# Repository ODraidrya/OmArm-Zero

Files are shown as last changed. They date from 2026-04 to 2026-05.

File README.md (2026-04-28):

# OmArm Zero

**6-DOF (5+1 Gripper) 3D-Printed Robotic Arm with ESP32 WiFi Web Control**

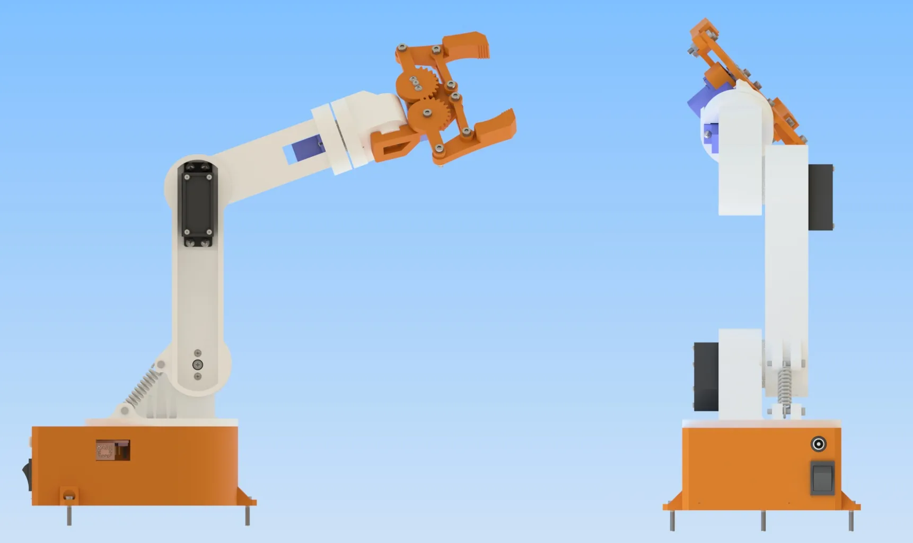
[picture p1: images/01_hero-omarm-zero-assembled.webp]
OmArm Zero






---

## Overview

OmArm Zero is a fully 3D-printed robotic arm with 6 degrees of freedom (5 arm joints + 1 gripper), controlled wirelessly over WiFi from any phone or laptop browser — no app required.

Connect to the ESP32's WiFi network, open `10.10.10.1` in any browser, and move the arm with sliders. Total cost: under $50.

## Specifications

| Parameter | Value |
|---|---|
| Degrees of Freedom | 6 (5 arm joints + 1 gripper) |
| Maximum Reach | 303 mm |
| Rated Payload | 141 g (150 g max) |
| Servos | 3x MG996R (metal gear) + 3x SG90 |
| Controller | ESP32 DevKit V1 |
| PWM Driver | PCA9685 16-channel (I2C) |
| Power | 5V 10A DC supply |
| WiFi | Access Point mode (no router needed) |
| Web Interface | Browser-based GUI with PWA support |
| Serial Interface | 115200 baud (ROS 2 compatible) |
| Total BOM Cost | ~$48 |

## Repository Structure

```
OmArm-Zero/
├── firmware/
│   ├── OmArmZeroControl/       # Main WiFi web control firmware
│   ├── OmArmZero_LittleFS/     # LittleFS uploader + web interface
│   │   └── data/               # HTML, CSS, JS served from ESP32 flash
│   ├── ros2_serial/            # Serial firmware for ROS 2 integration
│   └── test/
│       ├── I2C_Scanner/        # I2C device scanner (debug)
│       └── Calibration_SendToHome/  # Home position calibration (0°)
├── electronics/
│   ├── wiring-diagram.png      # Fritzing breadboard view
│   ├── omarm-zero.fzz          # Fritzing source file
│   └── bom.html                # Bill of Materials
├── images/                     # Documentation images
├── LICENSE                     # MIT License
└── README.md
```

## Quick Start

### 1. Hardware Required

| # | Component | Qty |
|---|---|-----|
| 1 | ESP32 DevKit V1 (30-pin) | 1 |
| 2 | PCA9685 16-Channel PWM Servo Driver | 1 |
| 3 | MG996R Servo Motor (metal gear) | 3 |
| 4 | SG90 Micro Servo | 3 |
| 5 | 5V 10A DC Power Supply | 1 |
| 6 | 686ZZ Bearing (6x13x5 mm) | 1 |
| 7 | Extension Spring (4 mm OD, 15 mm) | 1 |
| 8 | M3, M1.6, No.2, No.3 screws | assorted |

### 2. Wiring

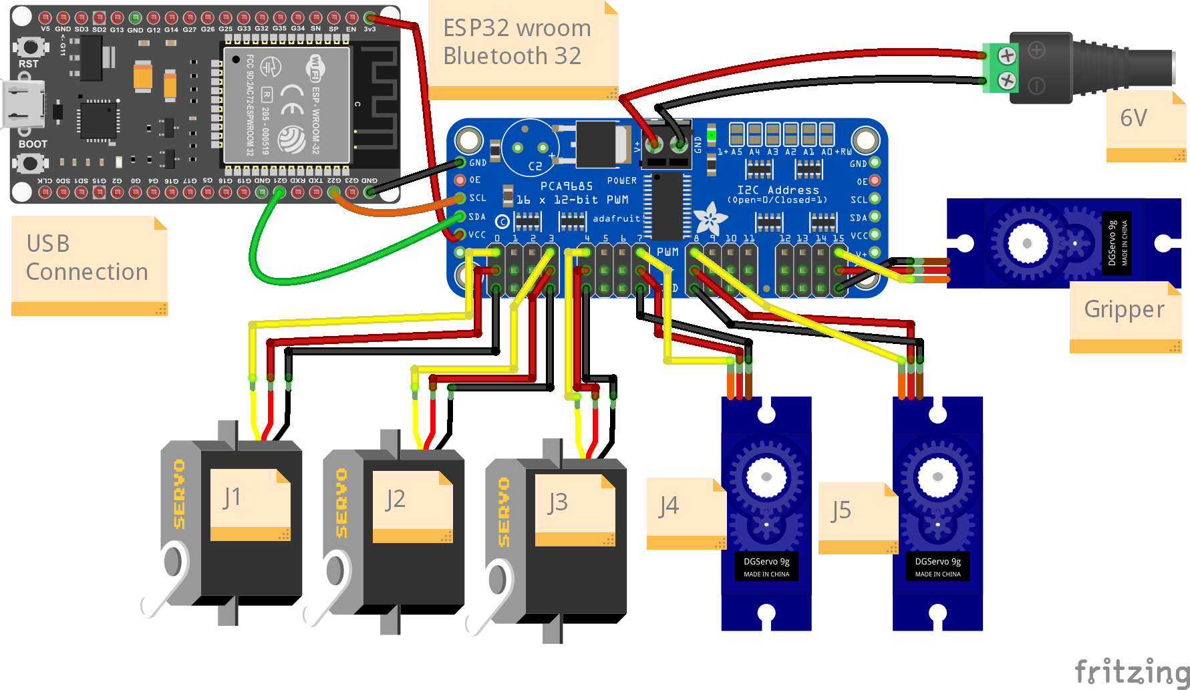
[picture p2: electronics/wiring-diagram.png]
Wiring Diagram


| PCA9685 Channel | Joint | Servo |
|---|---|---|
| 0 | J1 — Base rotation | MG996R |
| 1 | J2 — Shoulder | MG996R |
| 2 | J3 — Elbow | MG996R |
| 3 | J4 — Wrist pitch | SG90 |
| 4 | J5 — Wrist roll | SG90 |
| 5 | J6 — Gripper | SG90 |

**I2C connections:** PCA9685 SDA → GPIO 21, SCL → GPIO 22, Address: 0x40

**Power:** Connect the 5V 10A supply directly to the PCA9685 V+ terminal. Do NOT power servos from ESP32.

### 3. Flash Firmware

**Prerequisites:**
- Arduino IDE 2.x
- ESP32 board package (Espressif Systems)
- Libraries: `Adafruit_PWMServoDriver`, `Wire`, `WiFi`, `WebServer`, `LittleFS`

**Step 1 — Upload web interface to LittleFS:**

1. Install the [ESP32 LittleFS Upload Plugin](https://github.com/lorol/arduino-esp32littlefs-plugin)
2. Open `firmware/OmArmZero_LittleFS/OmArmZero_LittleFS.ino`
3. Use **Tools → ESP32 Sketch Data Upload** to flash the `data/` folder
4. Or: upload the sketch itself which creates the files programmatically

**Step 2 — Upload main firmware:**

1. Open `firmware/OmArmZeroControl/OmArmZeroControl.ino`
2. Select board: **ESP32 Dev Module**
3. Upload

### 4. Connect and Control

1. Power on the arm (5V supply + USB to ESP32)
2. Connect your phone/laptop to WiFi network: **OmArmZero**
3. Open browser: **http://10.10.10.1**
4. Move sliders to control each joint

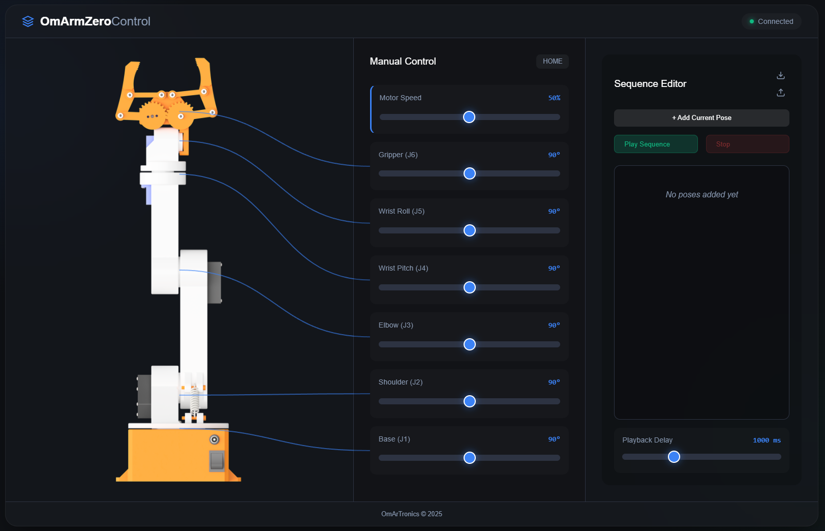
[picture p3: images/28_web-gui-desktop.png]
Web GUI


## Web Interface Features

- 6 individual joint sliders with real-time control
- Sequence recorder — save and replay motion sequences
- Home button — return all joints to 0° position
- PWA support — add to home screen for app-like experience
- Responsive design — works on mobile and desktop
- No internet required — runs entirely on ESP32's local network

## ROS 2 Integration

For ROS 2 Jazzy integration, flash `firmware/ros2_serial/omarm_zero_ros2_serial.ino` instead. This provides a serial protocol (115200 baud) compatible with the `ros2_control` hardware interface.

Serial command format: `J<joint_id>:<angle>\n` (e.g., `J1:90\n`)

## Calibration

Before first use, flash `firmware/test/Calibration_SendToHome/Calibration_SendToHome.ino` to set all servos to the 0° home position. Assemble the arm with all joints at 0°.

## Troubleshooting

| Issue | Solution |
|---|---|
| PCA9685 not found | Run `firmware/test/I2C_Scanner/` to check I2C address |
| Servos jitter | Ensure dedicated 5V 10A supply, not USB power |
| WiFi won't connect | Default SSID: `OmArmZero`, no password |
| Web page won't load | Verify LittleFS upload succeeded (Step 1) |

## 3D Print Files

STL files, STEP source, and the full 70-page PDF build guide are available as a complete package:

- **Cults3D:** [OmArm Zero — Complete Package](https://cults3d.com/en/3d-model/gadget/omarm-zero-6-dof-5-1-gripper-robotic-arm-esp32-wifi-control-stl-step)
- **OmArTronics Shop:** [Project Package](https://omartronics.com/product/omarm-zero-6dof-esp32-robotic-arm/)

## Links

- [Full Build Guide (Blog)](https://omartronics.com/omarm-zero-build-5-dof-robotic-arm-esp32-web-control/)
- [YouTube Build Video](https://youtu.be/smRG6uzNHag)
- [OmArTronics Website](https://omartronics.com/)

## License

This firmware is released under the **MIT License** — see [LICENSE](LICENSE).

**Note:** The 3D-printable CAD files (STL, STEP) and the PDF build guide are sold separately and are for personal, non-commercial use only. This repository contains only the firmware and web interface source code.

## Author

[OmArTronics](https://omartronics.com)

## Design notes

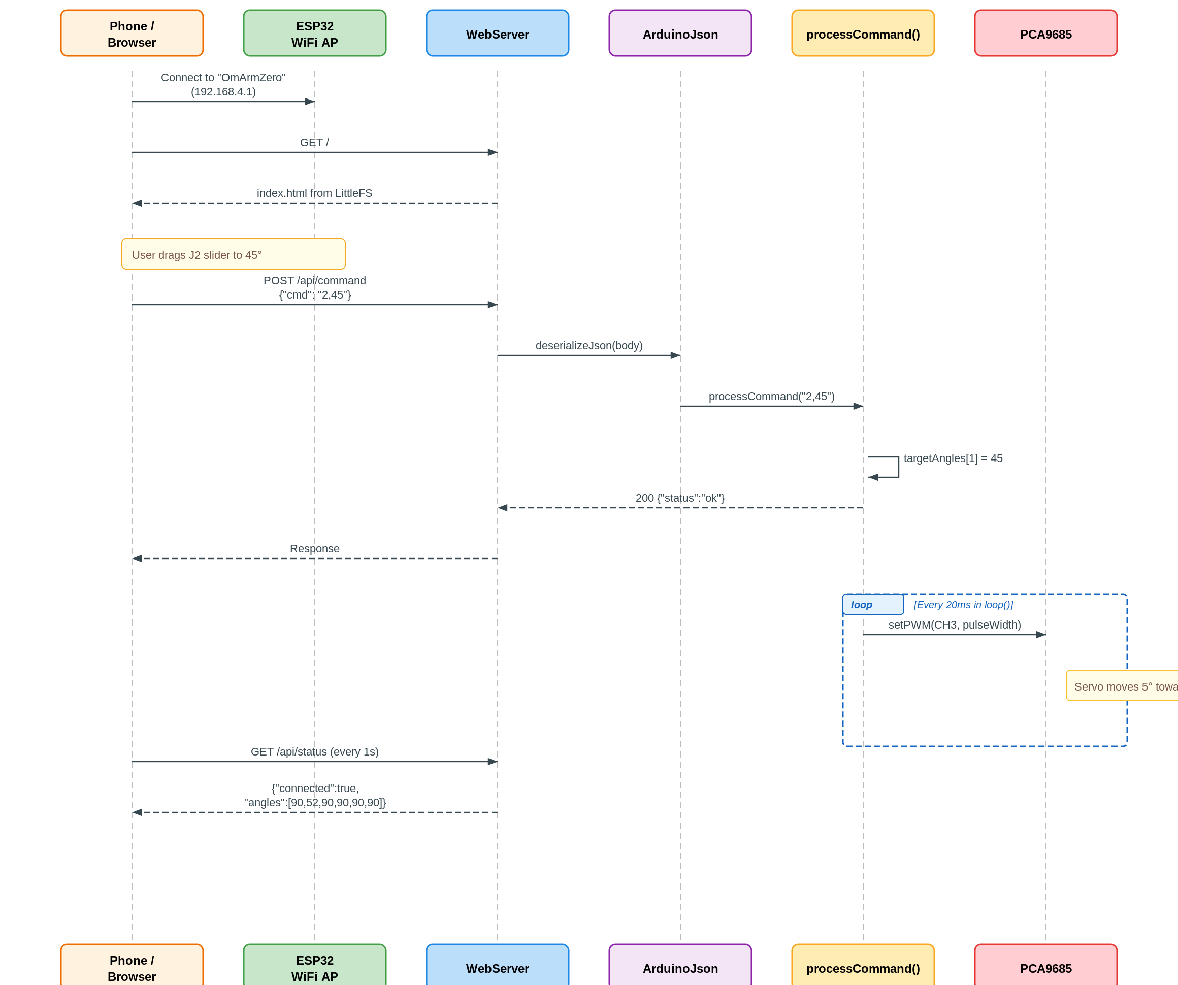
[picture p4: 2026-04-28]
images/08_web-gui-sequence-diagram.png

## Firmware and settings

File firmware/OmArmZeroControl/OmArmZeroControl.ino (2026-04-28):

/*
 * OmArm Zero Control Firmware
 * Für 6-DOF (5+1 Gripper) Roboterarm (6 Servos)
 * 
 * Hardware:
 * - ESP32 DevKit
 * - PCA9685 16-Channel PWM Driver (I2C: SDA=21, SCL=22)
 * - 3x MG996R Servo (J1, J2, J3)
 * - 3x SG90 Micro Servo (J4, J5, Gripper/J6)
 * 
 * Protokoll:
 * - Baud: 115200
 * - Commands:
 *   MOVE:d1,d2,d3,d4,d5,d6\n      - Move to positions (0-180°)
 *   HOME\n                        - Move to home position (0°)
 *   STATUS\n                      - Return current positions
 */

#include <Wire.h>
#include <Adafruit_PWMServoDriver.h>

// PCA9685 Setup
Adafruit_PWMServoDriver pwm = Adafruit_PWMServoDriver(0x40);

// Servo Configuration
#define NUM_SERVOS 6
// Channels für J1-J6 (Beibehalten der ersten 6 Kanäle des alten Codes)
const uint8_t SERVO_CHANNELS[NUM_SERVOS] = {0, 3, 4, 7, 8, 11};
const char* SERVO_NAMES[NUM_SERVOS] = {"J1", "J2", "J3", "J4", "J5", "Gripper"};

// PWM Pulse Width (us) for 0° and 180°
// MG996R (J1-J3): 500-2500us
// SG90 (J4-J6): 500-2400us
const uint16_t SERVO_MIN_PULSE[NUM_SERVOS] = {500, 500, 500, 500, 500, 500};
const uint16_t SERVO_MAX_PULSE[NUM_SERVOS] = {2500, 2500, 2500, 2400, 2400, 2400};

// Current positions (degrees 0-180)
int currentPos[NUM_SERVOS] = {0, 0, 0, 0, 0, 0};
int targetPos[NUM_SERVOS] = {0, 0, 0, 0, 0, 0};

// Safety limits (degrees)
const int MIN_ANGLE = 0;
const int MAX_ANGLE = 180;

// Movement speed (degrees per update cycle)
int movementSpeed = 5;
int updateIntervalMs = 20;  // 50Hz update rate

// Timing
unsigned long lastUpdateTime = 0;
unsigned long lastStatusTime = 0;

// Serial buffer
String serialBuffer = "";

void setup() {
  // Serial setup
  Serial.begin(115200);
  while (!Serial && millis() < 3000); // Wait max 3 seconds
  
  Serial.println("\n╔════════════════════════════════════════════╗");
  Serial.println("║  OmArm Zero Control Firmware             ║");
  Serial.println("║  Konfig: 6-DOF (5+1 Gripper, 6 Servos)   ║");
  Serial.println("╚════════════════════════════════════════════╝");
  
  // I2C Setup
  Wire.begin(21, 22); // SDA=21, SCL=22
  delay(100);
  
  // PCA9685 Setup
  pwm.begin();
  pwm.setOscillatorFrequency(27000000);
  pwm.setPWMFreq(50); // 50Hz for servos
  delay(100);
  
  Serial.println("✓ PCA9685 initialisiert");
  
  // Move to home position
  Serial.println("→ Fahre zu Home Position (0°)...");
  for (int i = 0; i < NUM_SERVOS; i++) {
    setServoAngle(i, 0);
    currentPos[i] = 0;
    targetPos[i] = 0;
    delay(50);
  }
  
  Serial.println("✓ System bereit!");
  Serial.println("Befehle: MOVE:d1,d2,d3,d4,d5,d6 | HOME | STATUS");
  Serial.println("─────────────────────────────────────────────");
}

void loop() {
  unsigned long now = millis();
  
  // Read serial commands
  readSerialCommands();
  
  // Smooth movement update at fixed rate
  if (now - lastUpdateTime >= updateIntervalMs) {
    lastUpdateTime = now;
    updateServoMovement();
  }
  
  // Periodic status (every 5 seconds if no commands)
  if (now - lastStatusTime > 5000) {
    lastStatusTime = now;
    // Uncomment for debug:
    // printStatus();
  }
}

void readSerialCommands() {
  while (Serial.available() > 0) {
    char c = Serial.read();
    
    if (c == '\n' || c == '\r') {
      if (serialBuffer.length() > 0) {
        processCommand(serialBuffer);
        serialBuffer = "";
      }
    } else {
      serialBuffer += c;
      
      // Safety: Prevent buffer overflow
      if (serialBuffer.length() > 128) {
        Serial.println("ERROR: Command too long");
        serialBuffer = "";
      }
    }
  }
}

void processCommand(String cmd) {
  cmd.trim();
  
  if (cmd.length() == 0) return;
  
  if (cmd.startsWith("MOVE:")) {
    handleMoveCommand(cmd.substring(5));
  }
  else if (cmd.startsWith("SPEED:")) {
    handleSpeedCommand(cmd.substring(6));
  }
  else if (isdigit(cmd.charAt(0))) {
    handleSingleJointCommand(cmd);
  }
  else if (cmd.equals("HOME")) {
    handleHomeCommand();
  }
  else if (cmd.equals("STATUS")) {
    handleStatusCommand();
  }
  else {
    Serial.print("ERROR: Unknown command: ");
    Serial.println(cmd);
  }
}

void handleSingleJointCommand(String cmd) {
  int commaIndex = cmd.indexOf(',');
  if (commaIndex == -1) return;
  
  int id = cmd.substring(0, commaIndex).toInt();
  int angle = cmd.substring(commaIndex + 1).toInt();
  
  // Convert 1-based ID to 0-based index
  int index = id - 1;
  
  if (index >= 0 && index < NUM_SERVOS) {
    angle = constrain(angle, MIN_ANGLE, MAX_ANGLE);
    targetPos[index] = angle;
  }
}

void handleMoveCommand(String params) {
  int values[NUM_SERVOS];
  int count = 0;
  
  // Parse comma-separated values
  int startIdx = 0;
  for (int i = 0; i <= params.length() && count < NUM_SERVOS; i++) {
    if (i == params.length() || params.charAt(i) == ',') {
      String val = params.substring(startIdx, i);
      val.trim();
      
      if (val.length() > 0) {
        values[count] = val.toInt();
        count++;
      }
      startIdx = i + 1;
    }
  }
  
  // Validate we got all values
  if (count != NUM_SERVOS) {
    Serial.print("ERROR: Expected ");
    Serial.print(NUM_SERVOS);
    Serial.print(" values, got ");
    Serial.println(count);
    return;
  }
  
  // Apply safety limits and set target positions
  for (int i = 0; i < NUM_SERVOS; i++) {
    int angle = constrain(values[i], MIN_ANGLE, MAX_ANGLE);
    
    if (angle != values[i]) {
      Serial.print("WARN: ");
      Serial.print(SERVO_NAMES[i]);
      Serial.print(" clamped ");
      Serial.print(values[i]);
      Serial.print("° → ");
      Serial.print(angle);
      Serial.println("°");
    }
    
    targetPos[i] = angle;
  }
  
  // Acknowledge
  Serial.println("OK: MOVE");
}

void handleSpeedCommand(String params) {
  int commaIndex = params.indexOf(',');
  if (commaIndex == -1) return;
  
  int newSpeed = params.substring(0, commaIndex).toInt();
  int newInterval = params.substring(commaIndex + 1).toInt();
  
  // Safety checks
  if (newSpeed >= 1 && newSpeed <= 20 && newInterval >= 5 && newInterval <= 50) {
    movementSpeed = newSpeed;
    updateIntervalMs = newInterval;
  }
}

void handleHomeCommand() {
  Serial.println("→ HOME");

  for (int i = 0; i < NUM_SERVOS; i++) {
    targetPos[i] = 0;
  }
  
  Serial.println("OK: HOME");
}

void handleStatusCommand() {
  Serial.print("STATUS:");
  for (int i = 0; i < NUM_SERVOS; i++) {
    Serial.print(currentPos[i]);
    if (i < NUM_SERVOS - 1) Serial.print(",");
  }
  Serial.println();
}

void updateServoMovement() {
  for (int i = 0; i < NUM_SERVOS; i++) {
    if (currentPos[i] != targetPos[i]) {
      
      // Move towards target with speed limit
      int diff = targetPos[i] - currentPos[i];
      int step = constrain(diff, -movementSpeed, movementSpeed);
      
      currentPos[i] += step;
      setServoAngle(i, currentPos[i]);
    }
  }
}

void setServoAngle(uint8_t servoIndex, int angle) {
  if (servoIndex >= NUM_SERVOS) return;
  
  // Clamp angle
  angle = constrain(angle, MIN_ANGLE, MAX_ANGLE);
  
  // Map angle to pulse width
  uint16_t minPulse = SERVO_MIN_PULSE[servoIndex];
  uint16_t maxPulse = SERVO_MAX_PULSE[servoIndex];
  uint16_t pulseWidth = map(angle, 0, 180, minPulse, maxPulse);
  
  // Convert to PCA9685 PWM value (4096 steps at 50Hz = 20ms)
  uint16_t pwmValue = (uint32_t)pulseWidth * 4096 / 20000;
  
  // Send to PCA9685
  pwm.setPWM(SERVO_CHANNELS[servoIndex], 0, pwmValue);
}

void printStatus() {
  Serial.println("\n─── Status ───");
  for (int i = 0; i < NUM_SERVOS; i++) {
    Serial.print(SERVO_NAMES[i]);
    Serial.print(": ");
    Serial.print(currentPos[i]);
    Serial.print("° → ");
    Serial.print(targetPos[i]);
    Serial.println("°");
  }
  Serial.println("──────────────");
}

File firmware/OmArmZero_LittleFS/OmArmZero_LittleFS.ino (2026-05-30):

/*
 * OmArm Zero LittleFS Firmware
 * 6-DOF (5+1 Gripper) Robot Arm (6 Servos) with Web Server + LittleFS
 * 
 * This version stores web files on the ESP32 filesystem (LittleFS).
 * Allows including large files like images.
 * 
 * Hardware:
 * - ESP32 DevKit
 * - PCA9685 16-Channel PWM Driver (I2C: SDA=21, SCL=22)
 * - 3x MG996R Servo (J1, J2, J3)
 * - 3x SG90 Micro Servo (J4, J5, Gripper/J6)
 * 
 * Upload Instructions:
 * 1. Install "ESP32 Sketch Data Upload" tool (Arduino 1.8) or use LittleFS plugin
 * 2. Tools -> ESP32 Sketch Data Upload (uploads /data folder)
 * 3. Upload this sketch normally
 * 
 * WiFi Access Point: "OmArmZero" (Password: "omarmcontrol")
 * Web Interface: http://10.10.10.1
 */

#include <Arduino.h>
#include <Wire.h>
#include <Adafruit_PWMServoDriver.h>
#include <WiFi.h>
#include <WebServer.h>
#include <LittleFS.h>
#include <ArduinoJson.h>

// WiFi Configuration
const char* ssid = "OmArmZero";
const char* password = "omarmcontrol";

// Web Server
WebServer server(80);

// PCA9685 Setup
Adafruit_PWMServoDriver pwm = Adafruit_PWMServoDriver(0x40);

// Servo Config
#define NUM_SERVOS 6
const uint8_t SERVO_CHANNELS[NUM_SERVOS] = {0, 3, 4, 7, 8, 11};
const uint16_t SERVO_MIN_PULSE[NUM_SERVOS] = {500, 500, 500, 500, 500, 500};
const uint16_t SERVO_MAX_PULSE[NUM_SERVOS] = {2500, 2500, 2500, 2400, 2400, 2400};

// State
int currentPos[NUM_SERVOS] = {0, 0, 0, 0, 0, 0};
int targetPos[NUM_SERVOS] = {0, 0, 0, 0, 0, 0};
int movementSpeed = 5;
unsigned long lastUpdateTime = 0;

// Function declarations
void setServoAngle(uint8_t servoIndex, int angle);
void updateServoMovement();
String getContentType(String filename);

// ------------------------------------------------------------------
// Web Server Handlers
// ------------------------------------------------------------------

void handleCommand() {
  if (!server.hasArg("plain")) {
    server.send(400, "application/json", "{\"error\":\"Body missing\"}");
    return;
  }
  
  String body = server.arg("plain");
  DynamicJsonDocument doc(512);
  if (deserializeJson(doc, body)) {
    server.send(400, "application/json", "{\"error\":\"Invalid JSON\"}");
    return;
  }

  String cmd = doc["cmd"];
  
  // STATUS check
  if (cmd.startsWith("STATUS")) {
    server.send(200, "application/json", "{\"status\":\"ok\"}");
    return;
  }
  
  // Joint Command: "1,90"
  if (isdigit(cmd.charAt(0))) {
    int comma = cmd.indexOf(',');
    if (comma != -1) {
      int id = cmd.substring(0, comma).toInt();
      int angle = cmd.substring(comma+1).toInt();
      if (id >= 1 && id <= 6) {
        targetPos[id-1] = constrain(angle, 0, 180);
      }
    }
  }
  // HOME
  else if (cmd.equals("HOME")) {
    for (int i = 0; i < 6; i++) targetPos[i] = 0;
  }
  // SPEED
  else if (cmd.startsWith("SPEED:")) {
    int comma = cmd.indexOf(',');
    if (comma != -1) {
      movementSpeed = cmd.substring(6, comma).toInt();
    }
  }
  // MOVE (Sequence Playback): "MOVE:90,90,90,90,90,90"
  else if (cmd.startsWith("MOVE:")) {
    String angles = cmd.substring(5);
    int idx = 0, start = 0;
    for (int i = 0; i <= angles.length() && idx < 6; i++) {
      if (i == angles.length() || angles.charAt(i) == ',') {
        targetPos[idx++] = constrain(angles.substring(start, i).toInt(), 0, 180);
        start = i + 1;
      }
    }
  }
  
  server.send(200, "application/json", "{\"status\":\"ok\"}");
}

// Serve files from LittleFS
void handleFileRequest() {
  String path = server.uri();
  
  if (path.endsWith("/")) {
    path += "index.html";
  }
  
  // Handle URL-encoded spaces
  path.replace("%20", " ");
  
  String contentType = getContentType(path);
  
  if (LittleFS.exists(path)) {
    File file = LittleFS.open(path, "r");
    server.streamFile(file, contentType);
    file.close();
  } else {
    server.send(404, "text/plain", "File Not Found: " + path);
  }
}

String getContentType(String filename) {
  if (filename.endsWith(".html")) return "text/html";
  else if (filename.endsWith(".css")) return "text/css";
  else if (filename.endsWith(".js")) return "application/javascript";
  else if (filename.endsWith(".json")) return "application/json";
  else if (filename.endsWith(".png")) return "image/png";
  else if (filename.endsWith(".jpg") || filename.endsWith(".jpeg")) return "image/jpeg";
  else if (filename.endsWith(".svg")) return "image/svg+xml";
  else if (filename.endsWith(".ico")) return "image/x-icon";
  return "text/plain";
}

// ------------------------------------------------------------------
// Setup & Loop
// ------------------------------------------------------------------

void setup() {
  Serial.begin(115200);
  
  // Initialize LittleFS
  if (!LittleFS.begin(true)) {
    Serial.println("LittleFS Mount Failed!");
    return;
  }
  Serial.println("LittleFS mounted successfully");
  
  // List files (debug)
  File root = LittleFS.open("/");
  File file = root.openNextFile();
  while (file) {
    Serial.print("  File: ");
    Serial.print(file.name());
    Serial.print(" (");
    Serial.print(file.size());
    Serial.println(" bytes)");
    file = root.openNextFile();
  }
  
  // I2C & PWM
  Wire.begin(21, 22);
  pwm.begin();
  pwm.setOscillatorFrequency(27000000);
  pwm.setPWMFreq(50);
  delay(100);

  // WiFi AP
  WiFi.mode(WIFI_AP);
  WiFi.softAP(ssid, password);
  delay(500);  // Wait for AP interface to fully initialize

  // Set static IP (must be AFTER softAP on ESP32)
  IPAddress local_IP(10, 10, 10, 1);
  IPAddress gateway(10, 10, 10, 1);
  IPAddress subnet(255, 255, 255, 0);
  WiFi.softAPConfig(local_IP, gateway, subnet);
  Serial.println("\n=================================");
  Serial.println("OmArmZero LittleFS Web Server");
  Serial.println("=================================");
  Serial.println("WiFi AP: " + String(ssid));
  Serial.print("IP: ");
  Serial.println(WiFi.softAPIP());
  Serial.println("=================================");

  // API endpoint
  server.on("/api/command", HTTP_POST, handleCommand);
  
  // Serve all other requests from LittleFS
  server.onNotFound(handleFileRequest);
  
  server.enableCORS(true);
  server.begin();
}

void loop() {
  server.handleClient();
  
  unsigned long now = millis();
  if (now - lastUpdateTime >= 20) {
    lastUpdateTime = now;
    updateServoMovement();
  }
}

// ------------------------------------------------------------------
// Servo Control
// ------------------------------------------------------------------

void updateServoMovement() {
  for (int i = 0; i < NUM_SERVOS; i++) {
    if (currentPos[i] != targetPos[i]) {
      int diff = targetPos[i] - currentPos[i];
      int step = constrain(diff, -movementSpeed, movementSpeed);
      currentPos[i] += step;
      setServoAngle(i, currentPos[i]);
    }
  }
}
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
